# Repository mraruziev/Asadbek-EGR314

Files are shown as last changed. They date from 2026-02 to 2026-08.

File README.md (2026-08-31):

# CropSCOUT — from a class project to robot working

This repository is where CropSCOUT started: my individual datasheet for **EGR 314** at ASU Polytechnic, Spring 2026, as part of Team 202 — the Crop S.C.O.U.T.S.

The assignment was an exploration rover. Seven of us built one in four months. My subsystem was mobility: a custom PCB around an **ESP32-S3-WROOM-1** driving four DC motors, two LEDs and two buttons, handling daisy-chain UART and MQTT with the rest of the team's boards. Input takes anything from 5 V to 40 V, regulated to 3.3 V by an LM2596S-3.3 and to 5.5 V by an LM2575-5.5.

Everything below the fold — requirements, block diagram, component selection, BOM, schematic, PCB layout, the full subsystem API — is that class work, unchanged.

## What happened next

We showed the rover to farmers in Uzbekistan expecting notes on the electronics. They asked when they could buy one.

So we stopped guessing and asked properly. **We interviewed 30 farmers** in Jizzakh, Surkhandarya and Shakhrisabz — what they grow, what eats their time, what eats their money, and what they would actually pay for. The answers were blunt:

- **14 of 30** named weeding as the job that takes the most time. Spraying was second.
- **8 of the 29** who answered named spraying as their single largest cash cost in a season.
- **12 of 30** said seasonal labour is hard to find at all.
- Shown three concepts, **18 of 30** picked the universal platform — the biggest, most capable one — and rated it **4.5 out of 5**.

That last one changed the plan. We had designed a small rover; farmers kept asking for a bigger one that could do more than one job on the same base. The V2 CAD is being drawn around that.

The full results, including the answers that contradict our pitch, are published live at **[crop-scout.com/survey](https://crop-scout.com/survey/)** — every figure computed from the database as responses arrive.

## Where it lives now

| | |
|---|---|
| **[crop-scout.com](https://crop-scout.com)** | The robot: what it does, the interactive demo, the field research |
| **[bestarorg.uz](https://bestarorg.uz)** | The venture behind it, and our other projects |
| **[Presentation](https://www.canva.com/design/DAHR2F0Cv24/_gwUxZhiubCPhxlqnAkmqw/view)** | CropSCOUT deck |

CropSCOUT is backed by **UzCombinator**, Batch 2, 2026.

## Founders

**Asadbek Ruziev** — electronics. Robotics Engineering at ASU, El-Yurt Umidi scholar. CAN-bus, motor control, the boards.

**Asror Uralov** — mechanical. Chassis, arms and attachment systems in SolidWorks.

**Samandar** — manufacturing engineer

## The code

The mobility subsystem runs MicroPython on the ESP32-S3: MQTT over TLS for commands and telemetry, a UART daisy chain to the other boards, and closed-loop control of the four motors.

**[`Motor subsystem/`](https://github.com/mraruziev/Asadbek-EGR314/tree/main/Motor%20subsystem)** — `main.py` (633 lines), `config.py`, and the `mqtt_as` async client.

## Demo

CropSCOUT demo (https://youtu.be/CgNYh9vksoY?si=Wh2rkczbTwafdUjh)

▶ **[Watch the demo](https://youtu.be/CgNYh9vksoY?si=Wh2rkczbTwafdUjh)**

## The datasheet

Live site: **[mraruziev.github.io/Asadbek-EGR314](https://mraruziev.github.io/Asadbek-EGR314/)**
Team 202 report: **[egr314-s-2026-202.github.io](https://egr314-s-2026-202.github.io/)**

Built with the rest of Team 202: Caleb Yuen, Cristopher Gutierrez, Jacob Alger, Aaron Kiem and Isaiah Johnston.
>>>>>>> d1ab0351fcce91105b6e6388854c63e64ff8db13

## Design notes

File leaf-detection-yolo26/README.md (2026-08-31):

# Leaf Detection YOLO26 Subsystem

Python subsystem for realtime leaf detection with Ultralytics YOLO26, PlantDoc object-detection training data, and PlantVillage/Chinese classification data for disease labeling.

## On macOS?

See `docs/macos_quickstart.md`. The commands below are PowerShell and assume CUDA;
the macOS path uses `--device mps`, needs no Kaggle or Roboflow account, and gets you
a working webcam demo with:

```bash
./.venv/bin/leaf-download-plantvillage-hf --out data/processed/plantvillage_cls
./.venv/bin/leaf-train classify --config configs/training/classify_plantvillage.yaml --epochs 8 --batch 64 --device mps
./.venv/bin/python webcam.py
```

## Current Assumptions

- `YOLO26` means the current Ultralytics YOLO26 family, starting with `yolo26n.pt` for realtime detection.
- `PlantDoc` is the primary detector dataset because it has bounding boxes.
- `PlantVillage` is image-level classification data, so it feeds the classifier branch by default. Pseudo-box conversion is available only for baseline experiments.
- The requested Chinese dataset is treated as the AI Challenger 2018 Agricultural Disease dataset unless you specify a different source.
- Claude is not invoked by this repo. `CLAUDE.md` is included so Claude Code can safely pick up context if you run it separately.

## Setup

```powershell
cd C:\Users\abbos\source\leaf-detection-yolo26
python -m venv .venv
.\.venv\Scripts\Activate.ps1
python -m pip install --upgrade pip
pip install -r requirements.txt
pip install -e .
```

For GPU training, install the PyTorch build matching your CUDA version before installing `ultralytics`.

## Data Layout

```text
data/
  raw/
    plantdoc/                 # Roboflow YOLO export with data.yaml
    plantvillage/             # Kaggle download
    chinese/                  # Requested dataset when received
  processed/
    plantvillage_cls/         # YOLO classification folder layout
    plantvillage_pseudo_yolo/ # Optional weak detection labels
runs/
  detect/
  classify/
```

## Download PlantDoc

Preferred path is a Roboflow YOLOv8/YOLO export.

```powershell
copy .env.example .env
# Fill ROBOFLOW_API_KEY in .env
leaf-download-plantdoc --out data/raw/plantdoc
leaf-validate-yolo --dataset data/raw/plantdoc
```

If Roboflow gives you a direct export ZIP URL:

```powershell
leaf-download-plantdoc --url "https://..." --out data/raw/plantdoc
```

## Download PlantVillage

Install Kaggle credentials as `%USERPROFILE%\.kaggle\kaggle.json` or set `KAGGLE_USERNAME` and `KAGGLE_KEY`.

```powershell
leaf-download-plantvillage --dataset emmarex/plantdisease --out data/raw/plantvillage
leaf-prepare-plantvillage --source data/raw/plantvillage --out data/processed/plantvillage_cls --overwrite
```

## Train

Detector:

```powershell
leaf-train detect --config configs/training/detect_plantdoc.yaml
```

Classifier:

```powershell
leaf-train classify --config configs/training/classify_plantvillage.yaml
```

Dry-run either command before spending GPU time:

```powershell
leaf-train detect --config configs/training/detect_plantdoc.yaml --dry-run
```

## Realtime Inference

Disease classifier only, no detector weights needed. The classifier reads a centre
crop of the frame, so fill that box with one leaf:

```powershell
leaf-realtime --classifier runs/classify/plantvillage_yolo26n_cls/weights/best.pt --source 0
```

Detector only:

```powershell
leaf-realtime --detector runs/detect/plantdoc_yolo26n/weights/best.pt --source 0
```

Detector plus disease classifier:

```powershell
leaf-realtime `
  --detector runs/detect/plantdoc_yolo26n/weights/best.pt `
  --classifier runs/classify/plantvillage_yolo26n_cls/weights/best.pt `
  --source 0
```

Press `q` to stop the preview window.

## Export

```powershell
leaf-export --model runs/detect/plantdoc_yolo26n/weights/best.pt --format onnx --imgsz 640
```

Use TensorRT only on a matching NVIDIA deployment machine:

```powershell
leaf-export --model runs/detect/plantdoc_yolo26n/weights/best.pt --format engine --device 0 --half
```

## Optional Weak Detection From PlantVillage

PlantVillage does not provide bounding boxes. If you need one combined detector baseline anyway:

```powershell
leaf-pseudo-yolo --source data/processed/plantvillage_cls --out data/processed/plantvillage_pseudo_yolo --overwrite
```

This creates one full-image bounding box per classification image. Treat resulting metrics as a weak baseline, not as production detector quality.

## Source References

- Ultralytics YOLO26 detection/training/export docs: https://docs.ultralytics.com/tasks/detect/
- Ultralytics Python usage docs: https://docs.ultralytics.com/usage/python/
- PlantDoc Roboflow public dataset: https://public.roboflow.com/object-detection/plantdoc/
- PlantVillage Kaggle dataset requested: https://www.kaggle.com/datasets/emmarex/plantdisease?select=PlantVillage
- AI Challenger 2018 Chinese agricultural disease candidate: https://spj.science.org/doi/10.34133/plantphenomics.0208

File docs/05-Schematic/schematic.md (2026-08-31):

---
title: Module Schematic
---

### Overview
This schematic is designed to support 4 motors, motor drivers, ESP32 subsystem. I will also be sending and receiving data through TX and RX of the 8-pin headers. Some symbols were sourced from the Digikey website, while a few others were from the KiCad library.

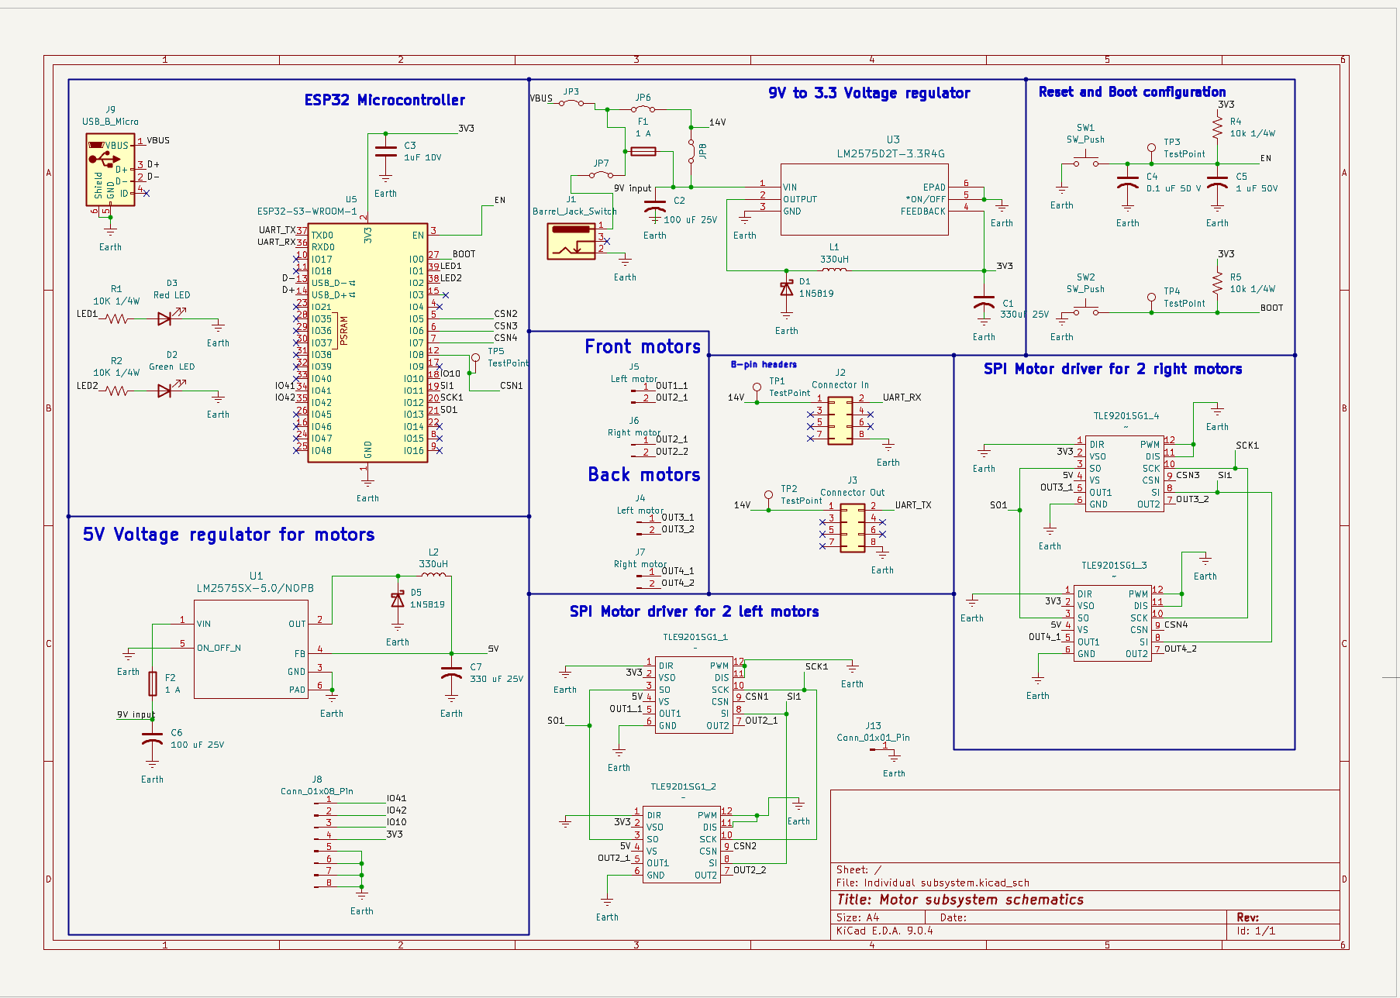
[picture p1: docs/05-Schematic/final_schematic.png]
schematic

**Figure 1:** Showing my schematic

### Key functional blocks

## 1. Microcontroller interface
* ESP32-S3-WROOM-1
* UART daisy chain interface 
* USB for programming
* Boot, reset buttons
* Extra pins for other potential usage
The ESP32 microcontroller is included in this schematic.

## 2. Motor Driver
* SPI configuration (SCLK, SDI, SDO, NSCS)
* PWM → PWM is not going to be used since it is SPI, so it will be grounded
* DIR → direction grounded (not used)
* DIS → enable/disable
* VSO 
I am also going to use 4 motor drivers. The motor driver is a surface-mount H-bridge. Out1 and Out2 allow control of the speed, and input comes from the GPIO pins of the ESP32, while output goes to the motors.

## 3. Shared SPI
* GPIO11 → SI on all drivers
* GPIO13 ← SO on all drivers
* GPIO12 → SCK on all drivers
Since I am going to use 4 motors together, I will have 3 shared SPI pins that go to the same ESP32 GPIO as above.

## 4. UART
* TX1
* RX1 
Since UART0 - TX0, RX0 gave me problems during the daisy chain, I updated the schematic to swap UART pins.

## 5. Motors
I am going to use 2 headers for each of my motors, as they can not be surface-mount. In total, I will be using 4 motors that will be working with 4 motor drivers.
* 200 RPM 3-6V DC Gearmotor

## 6. Power Management
* 9V barrel jack for motors
* LM2575D 3.3 Voltage regulator
* LM2575D 5.5 Voltage regulator for motor movement
* Fuse for both barrel jacks for safety
* The input power can be anywhere from 5V to 40 volts.
* If using team power, connect jumpers at JP6 and JP7
* For individual power supply, connect JP3
* For using motors with their own power, use JP7

## Resources

The schematic as a PDF download is available [*here*](Final_schematic.pdf), and the Zip folder of the project [*here*](EGR314-kicad-final.zip).

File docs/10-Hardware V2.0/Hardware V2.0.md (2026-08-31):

---
title: Module Hardware V2
---

### Overview
Improvement 1: If I were to make a new PCB, I would try to use.STL files from the Digikey design, so that before ordering the PCB, I know how my component aligns properly with the footprint. The footprint for the inductor was quite different than the actual size of the inductor I used. I would start my PCB design earlier, as most of my PCB problems were because I started it a bit late. 

<br> 
Improvement 2: I would also try to use Cadence next time with its auto-tracing feature, or trace components better on KiCad. My traces were too small, and this could have affected my motor driver. The power was not coming to my motor driver, even if I made 3 PCBs.

<br> 
Improvement 3: I would try to make my LEDs and resistors a bit bigger, allowing me to solder more easily, and since there are bigger surface-mount components available. I will try to research more on different sizes of components, allowing me to have a better design. 

<br> 
Improvement 4: I would also choose bigger wheels and bigger motors with high torque and more RPM. Also, I would try to use I2C-based motor drivers instead of SPI for my motors since my motors were working fine without a daisy chain. But when I was getting commands for motor movements, my motors would move endlessly and not accept other commands. This also means that my motor drivers will need more input power, so I would change my voltage regulator to a 12V regulator. 

<br>
Improvement 5: I would try to reduce the PCB size and make holes to mount the PCB. This would have been very helpful to reduce manufacturing costs and learn a better way.

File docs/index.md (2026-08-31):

---
title: Welcome
tags:
- tag1
- tag2
---
<center>
<font size= "6">Asadbek Ruziev Datasheet</font><br>
as part of<br>
<font size= "8"> Exploration Device Project</font><br>
for<br>
<font size= "5"> Crop S.C.O.U.T.S. </font><br>

<font size= "5"> Team 202 </font><br>

**Submission: May, 4, 2026**
</center>

## Introduction

* Hi! I am highly passionate about mobile robotics for agriculture and ecology. Through my work at CropSCOUT at EGR 314, I gained in-depth knowledge and experience that I plan on using in future projects.

### Project Summary

* I am responsible for mobillity of <ins>the rover project.</ins> We are a team of 7 engineering students who are designing an explorative rover in 4 months. Please, take a look at the process of our design through the different tabs in the team report. fF you would like to learn more about other team members' subsystems, access the team report and follow the link for each member's website.
* To get more information about our teamwork, follow Team 202 [Team report.](https://egr314-s-2026-202.github.io/)

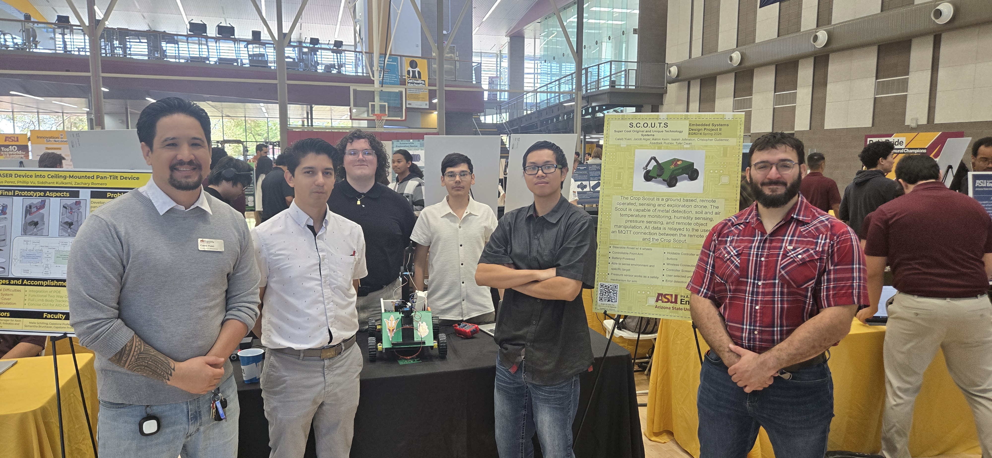
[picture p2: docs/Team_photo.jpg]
Team picture

>From left ro right: Cale Yuen, Cristopher Gutierrez, Jacob Alger, Asadbek Ruziev, Aaron Kiem, Isaiah Johnston

### My Contribution 

* Our team is focused on making a land-based explorative rover project that drives to different places and uses its sensors to perform measurements. The Crop Scout is a ground-based, remotely operated, sensing and exploration rover. It is capable of going to any place and detecting metal, measuring temperature, and humidity. All data works through an MQTT connection and a UART
* I am responsible for the mobility of the rover using ESP32. I will be using 4 motors with wheels attached. Motors will be working through the motor driver to move the robot from a distance through WiFi.

To review the details listed of the material used to construct the subsection, you can review it in the ["Team"](https://egr314-s-2026-202.github.io/) section of the datasheet.

## Showcase Video Demo

<iframe width="560" height="315" src="https://www.youtube.com/embed/CgNYh9vksoY?si=5lFRXKqbXAz6XXHL" title="YouTube video player" frameborder="0" allow="accelerometer; autoplay; clipboard-write; encrypted-media; gyroscope; picture-in-picture; web-share" referrerpolicy="strict-origin-when-cross-origin" allowfullscreen></iframe>

To review the details of the data sheet, hyperlinks are provided below: <br>
[1. Requirements](https://mraruziev.github.io/Asadbek-EGR314/01-Requirements/Requirements/) <br> 
[2. Block Diagram](https://mraruziev.github.io/Asadbek-EGR314/02-Block-Diagram/Block-Diagram/) <br> 
[3. BOM](https://mraruziev.github.io/Asadbek-EGR314/04-BOM/BOM/) <br> 
[4. Component Selection](https://mraruziev.github.io/Asadbek-EGR314/03-Component-Selection/Component-Selection/) <br> 
[5. Schematic](https://mraruziev.github.io/Asadbek-EGR314/05-Schematic/schematic/) <br> 
[6. PCB Design](https://mraruziev.github.io/Asadbek-EGR314/06-PCB/pcb/)  <br>
[7. API](https://mraruziev.github.io/Asadbek-EGR314/07-API/API/) <br>
[8. Schematic](https://mraruziev.github.io/Asadbek-EGR314/08-Resources/Resources/) <br> 
[9. Reflections](https://mraruziev.github.io/Asadbek-EGR314/09-Lessons%20Learned/Lessons%20learned/)  <br>
[10. Hardware V2.0](https://mraruziev.github.io/Asadbek-EGR314/10-Hardware%20V2.0/Hardware%20V2.0/) <br>
[11. Appendix](https://mraruziev.github.io/Asadbek-EGR314/Appendix/) <br>

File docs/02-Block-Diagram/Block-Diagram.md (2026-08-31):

---
title: Module's Block Diagram
tags:
- tag1
- tag2
---

## Overview
Purpose of having block diagram is to help visualise my subsystem so that you can understand the workflow of code and schematics better. I have included 2 motors that are going to be parallel on the right. 2 motors on the left will also work together. I have planned to make the rover working with 2 motors together on each side, then making chassis as my stretch goal. This block diagram clearly shows how power, control and data will be floweing through my subsystem and to make the whole rover system work. Mobility of the rover is crucial to successfull launch of the project.

<br> <br>

## Asadbek's Block Diagram 
Showing my screenshot of the block diagram here

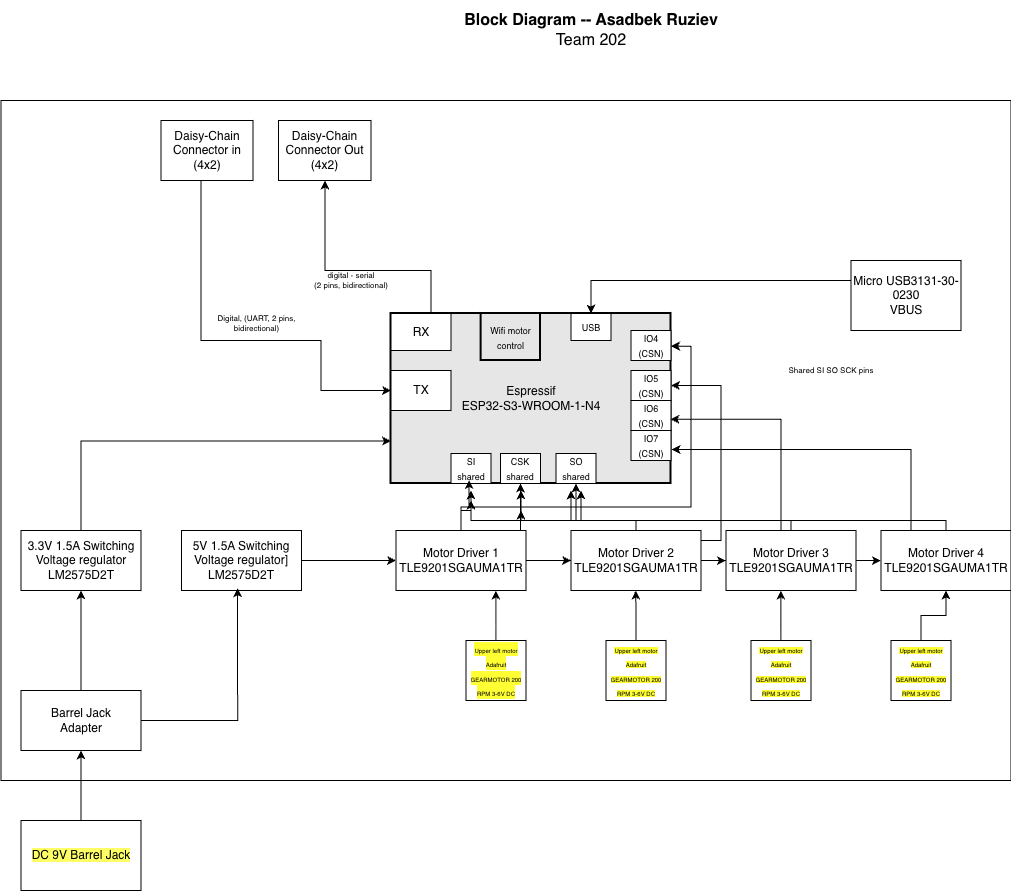
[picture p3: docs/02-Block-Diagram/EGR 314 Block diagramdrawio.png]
My Indivial Block diagram


### Impoortant Things to mention are following:
* ESP32-S3-WROOM-1
* 4 Motor Drivers
* 4 Motors
* Voltage regulator: 1 barrel jack  is going to be used twice through shared power for the team and inidividually. I will use 2 voltage regulatorsand one of them will be to convert voltage into the 3.3 V and 6V.
* Daisy chain connectors through 8-pin header connectors Connector In (4×2), Connector Out (4×2) and UART communication.
* USB
* Power levels: Unregulated power levels are going to be 9V for the motors, but the input to ESP 32 is 3.3V. For logic-level peripherals of my subsystem's ESP 32 I will use 3.3 volts. 
* Actuator: I will be using 4 same DC motors for smooth operation of the rover. 
* Team connections: I will be connecting my ESP32 to Caleb's board to oeprate better through RX and TX 
* Power source: barrel jack for the motors are main sources of power. 

SPI UART serial communication protocols are just alternative communication ways to connect to motors actuators sensor. All WiFi is done by esp32. 

Decision-making process: My block diagram meets project requirements by following the requirement TR-01(mobillity of the rover) and helping with Wi-Fi/MQTT of the rover.

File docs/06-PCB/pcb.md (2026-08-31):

---
title: PCB
---
## Overview
This section is an overview of the PCB design for the Metal detection system for the CropScout. Some of the footprints are from the Digikey.

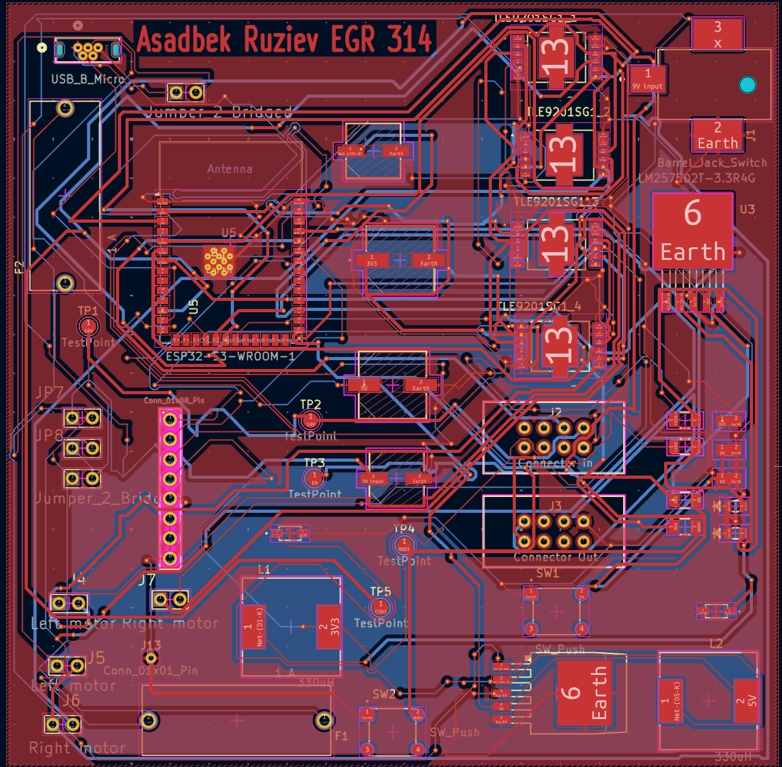
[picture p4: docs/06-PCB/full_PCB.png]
View


**Figure #1:** Full View of PCB.

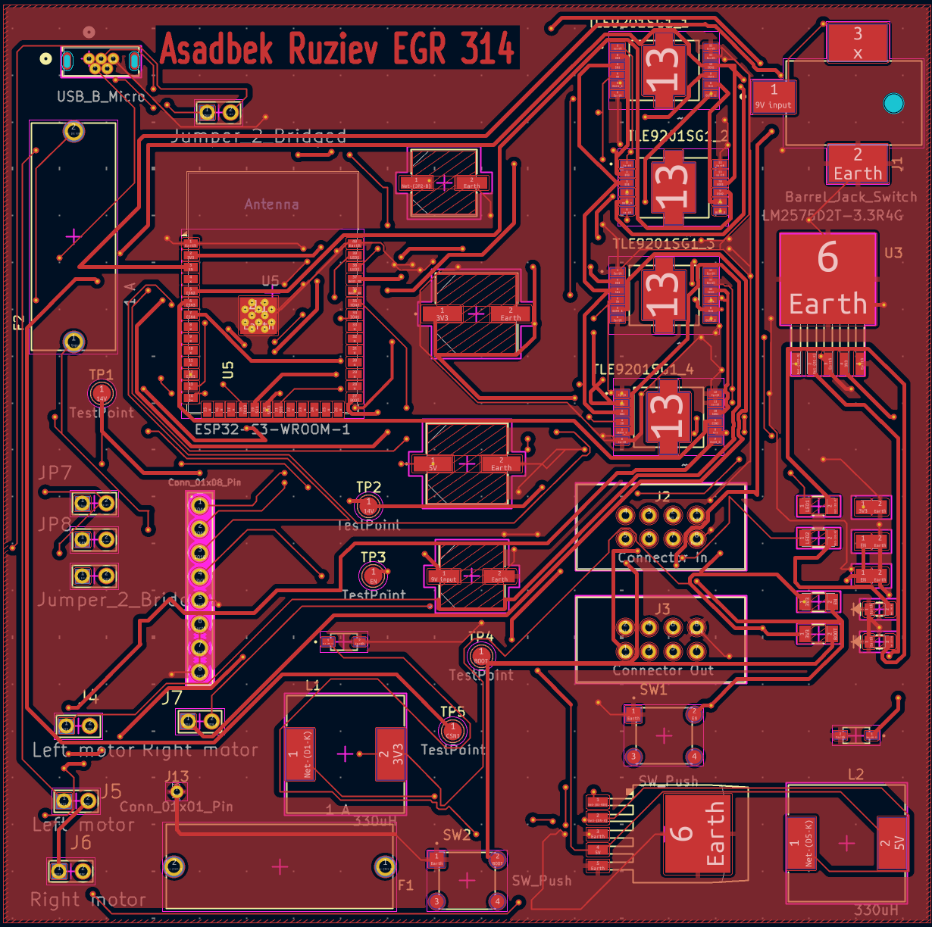
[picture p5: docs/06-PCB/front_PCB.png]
Front


**Figure #2:** Front View of PCB.

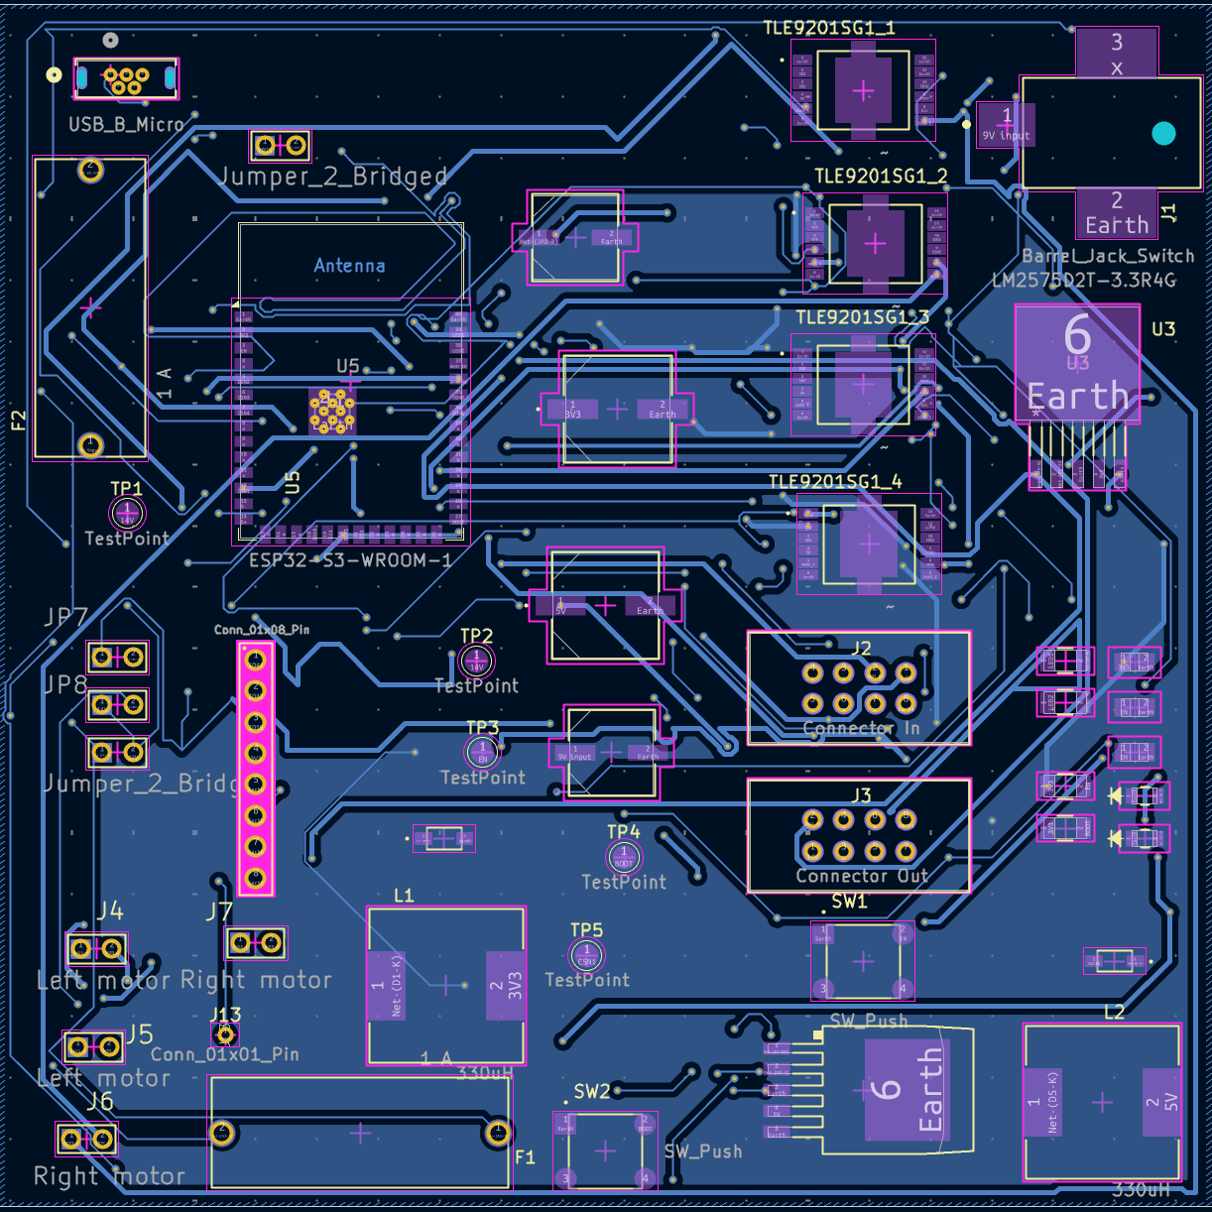
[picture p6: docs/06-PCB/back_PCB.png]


**Figure #3:** Back View of PCB.

<<<<<<< HEAD
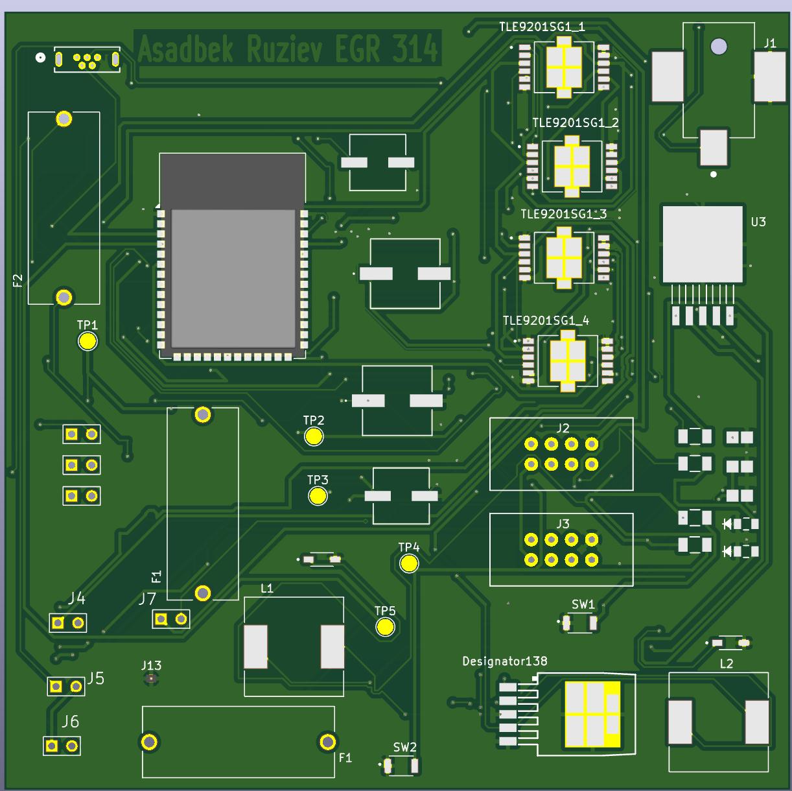
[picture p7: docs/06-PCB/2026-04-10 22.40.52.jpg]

=======
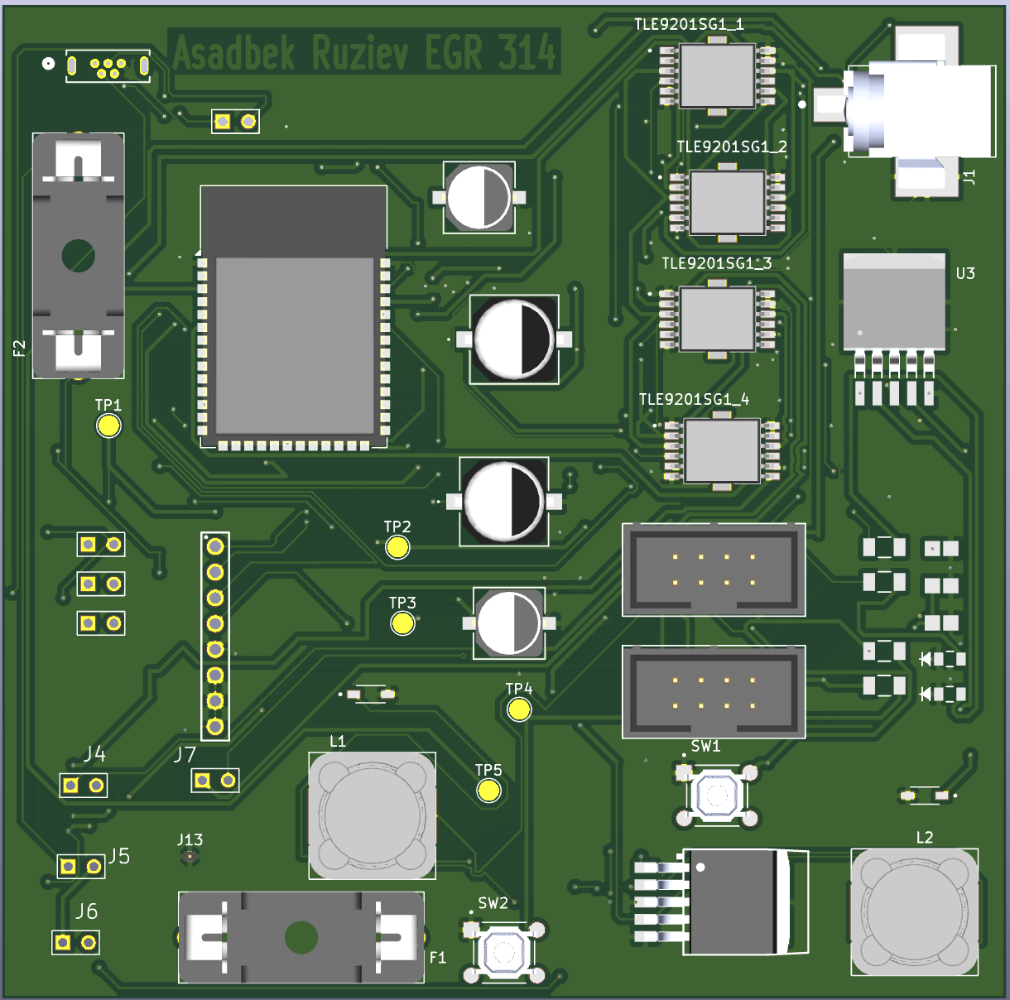
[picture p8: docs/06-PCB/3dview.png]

>>>>>>> d1ab0351fcce91105b6e6388854c63e64ff8db13

**Figure #4:** 3D View of PCB.

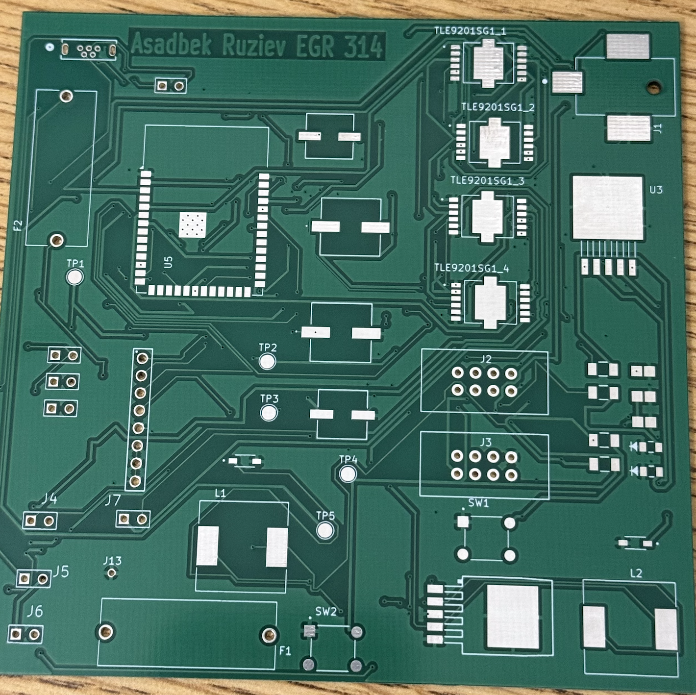
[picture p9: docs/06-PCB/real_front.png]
Front


**Figure #5:** FrManufactured Front View of PCB.

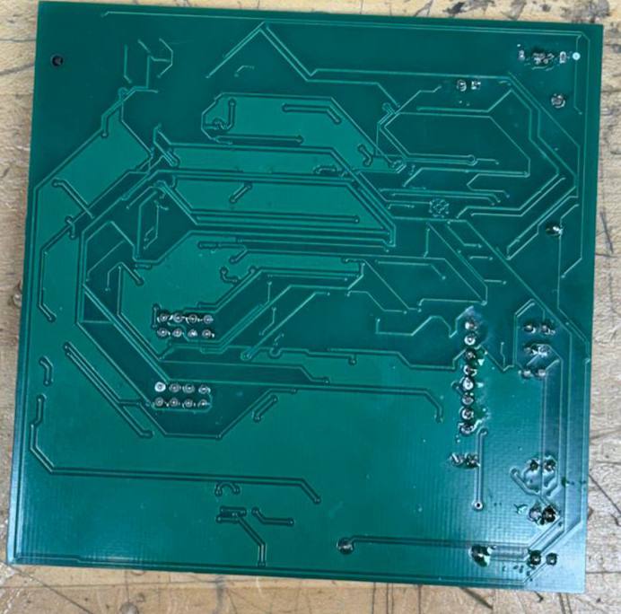
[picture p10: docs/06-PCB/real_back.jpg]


**Figure #6:** JLCPCB Back View of PCB.

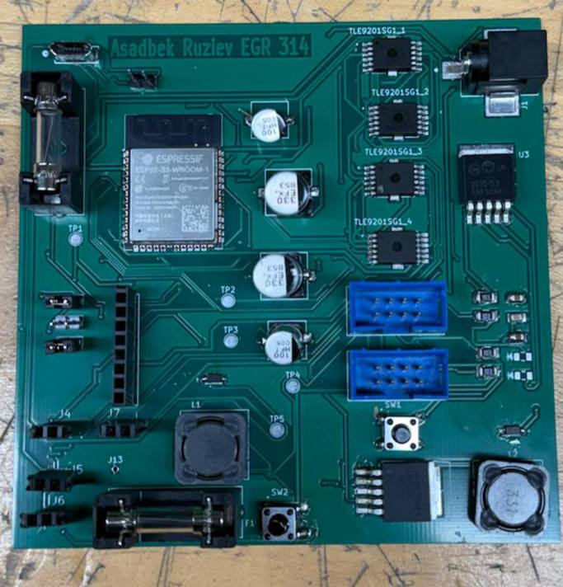
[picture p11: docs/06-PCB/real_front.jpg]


**Figure #7:** Soldered View of PCB connected to team Daisy Chain

**Resources**
Individual subsystem.zip

The zip folder of the project [*here*](Individual subsystem april version.zip).
The gerber files of the project [*here*](gerber.zip).

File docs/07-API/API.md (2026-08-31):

---
title: Mobillity API
---

## Overview
This page exists to show the API messaging of the Wheel and mobillity subsystem. API stands for Application Programming Interface.
The following are messages sent and received to my board. Some messages get passed from me, as my subsystem will check the message and send it to the next person.
The subsystem's ID is "w".

Cristopher sends me a message via MQTT/WiFi, and I verify it. I use it to send it back to him. He forwards it to Jacob. Jacob will share the wheel commands with my board. Each message will have a destination type instead of being a loop source. It is also broadcasted used for everyone. Messages will be done one by one, as it is a daisy chain.

### All Subsystem IDs

| Subsystem | Identifier | Person |
| --- | --- | --- |
| HMI | h | Jacob |
| Communication | c | Cris |
| Wheels | w | Asadbek |
| Pressure/Accelerometer  | p | Tyler |
| Front Arm | a | Caleb |
| Metal Detector | m | Aaron |
| Temperature/Humidity | t | Isaiah |
| Broadcast | X | System-Wide Messaging |

## Message data types

| Description | Prefix |
| --- | --- |
| String (ASCII char array)| S: |
| Integer (8 Bit) | I: |
| Integer (16 Bit) | IL: |
| Float (32 Bit) | F: |

## Received Messages
- Message framing for single-character subsystem IDs 
- AZ [Sender] [Receiver] [Data in the message (1-58 bytes) ] BY
- | WD:S:F |
- | WD:S:B |
- | WD:S:R |
- | WD:S:L |
The wheel subsystem will receive drive commands from the HMI and start broadcasting. Those commands are processed and sent back to the HMI with the values I receive over UART.

If Jacob/HMI is commanding wheels:
* Forward: AZhwWD:S:F;YB
* Backward: AZhwWD:S:B;YB
* Right: AZhwWD:S:R;YB
* Left: AZhwWD:S:L;YB
Start broadcast to everyone:
* AZhXST:S:Start;YB
If Chris/Communication is checking wheel Bluetooth:
* AZcwBT:S:check;YB
If you want to force-stop for testing, your current wheel code also supports:
* AZhwWD:S:S;YB

### Message Type -- Start Broadcast

As shown above, this is broadcast message for my board: `AZhXST:S:Start;YB`

| Bytes 1–3 | Bytes 4–5 | Bytes 6–11 |
| --- | --- | --- |
| **Name** | **Type**  | **Data** |
| ST: | S: | Start; |
| **Min** | | Start; |
| **Max** | | Start; |
| **Example** ST: | S: | Start; |

### Message Type -- Wheel Drive Mode

Receives the direction command from the HMI D-Pad and drives the wheels accordingly.

`AZhwWD:S:F;YB`

| Bytes 1–3 | Bytes 4–5 | Bytes 6–7 |
| --- | --- | --- |
| **Name** | **Type**  | **Data** |
| WD: | S: | F; / B; / R; / L; |
| **Min** | | F; / B; / R; / L; |
| **Max** | | F; / B; / R; / L; |
| **Example** WD: | S: | F; |

## Behaviour check
- Check whether the format of the message packet is valid
- Check if it is for the wheel subsystem
- Check the destination if not

## Receiving messages

When a byte comes through the UART/MQTT to my board
1. Look for the AZ packet prefix, and anything non-related is discarded
2. I read bytes into a buffer till suffix BY is found or the buffer limit of 62 bytes is exceeded.
3. If receiver == w (my board), the message is parsed
4. If receiver == X (broadcast), the message is parsed and processed
5. If the message receiver is not me, the packet is going to be forwarded out the downstream UART byte-for-byte

| Section | Bytes amount | Name of the variable | Tpe ID | Example for the code |
| :---- | :---- | :---- | :---- | :---- |
| Type ID | 5 | S | char | S |
| Variable | 2 | WD | char | WD |
| Seperator | 1 |  | char | : |
| Terminator value | 1 | DRCTN | char | : |
| Value | 1 |  | char |  |

Overall message bytes: 12

## Sending messages
| Section | Bytes amount | Name of the variable | Tpe ID | Example for the code |
| :---- | :---- | :---- | :---- | :---- |
| Type ID | 5 | S | char | S |
| Variable | 1 | : | char | ST |
| Seperator | 1 | : | char | : |
| Terminator value | 1 | DRCTN | char | : |
| Value | 1 | Start | char | Start |

Overall message bytes: 12

Example: AZhXST:S:Start;YB

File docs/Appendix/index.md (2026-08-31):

---
title: Appendix - Main Page
---

>The Appendix is where supporting information goes that is not in the main body. 

## Appendix Content

* [Microcontroller selection](https://mraruziev.github.io/Asadbek-EGR314/Appendix/02-Microcontroller-Selection/esp-32-table/)
* [Power budget](https://mraruziev.github.io/Asadbek-EGR314/Appendix/02-Power-Budget/Power-Budget/)

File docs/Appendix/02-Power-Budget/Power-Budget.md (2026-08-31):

---
title: Appendix - Power Budget
---

## Overview
Power Budget helps to understand more about the maximum current draw. This helsp to understand the choice of appropariate fuse. The power budget also helps to know if the subsystem is going to operate in different current scenarios.

> Capture your power budge as a image to display. Take time to get clean breaks and a well organized layout.

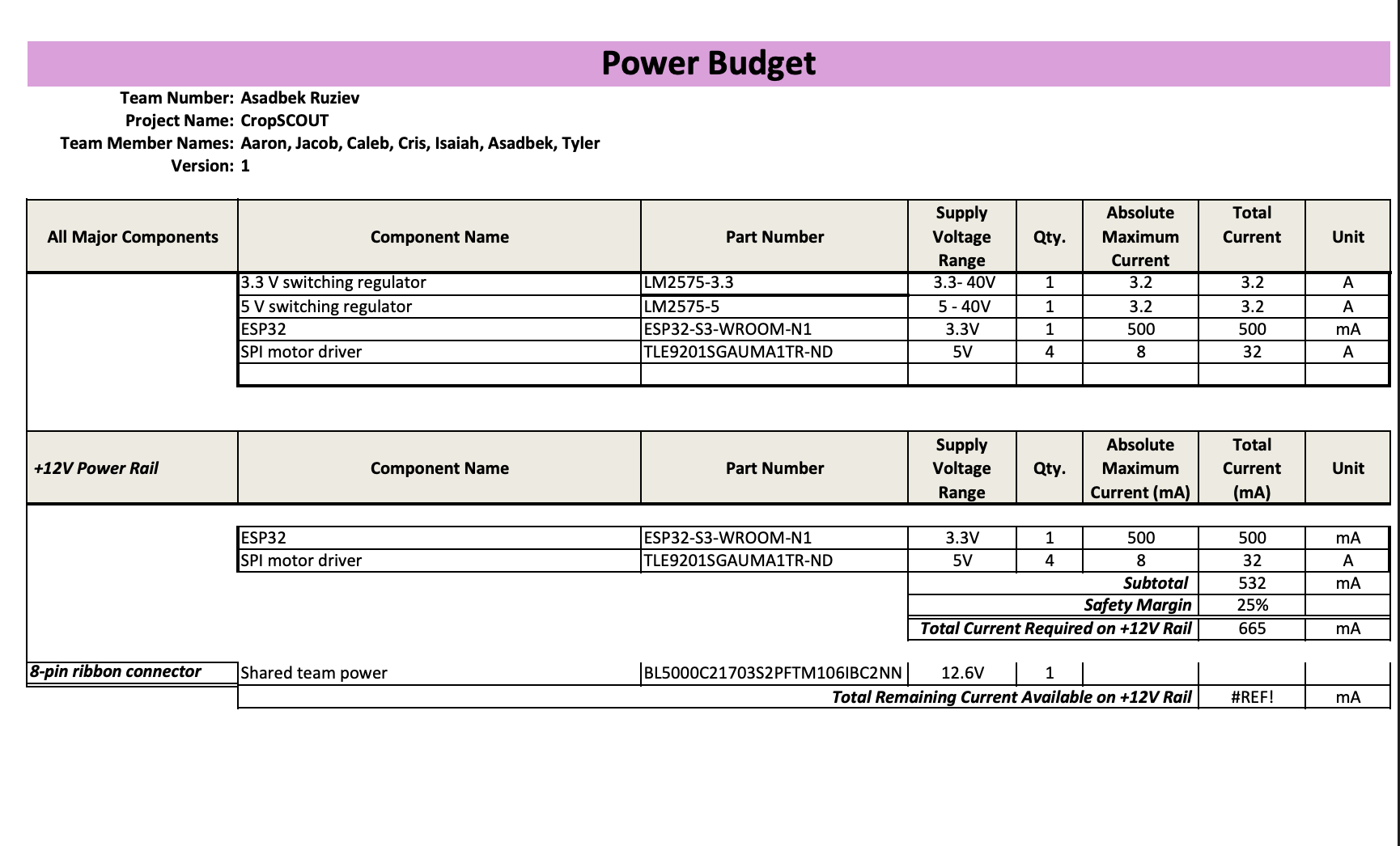
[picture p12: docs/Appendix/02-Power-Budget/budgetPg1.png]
budget1


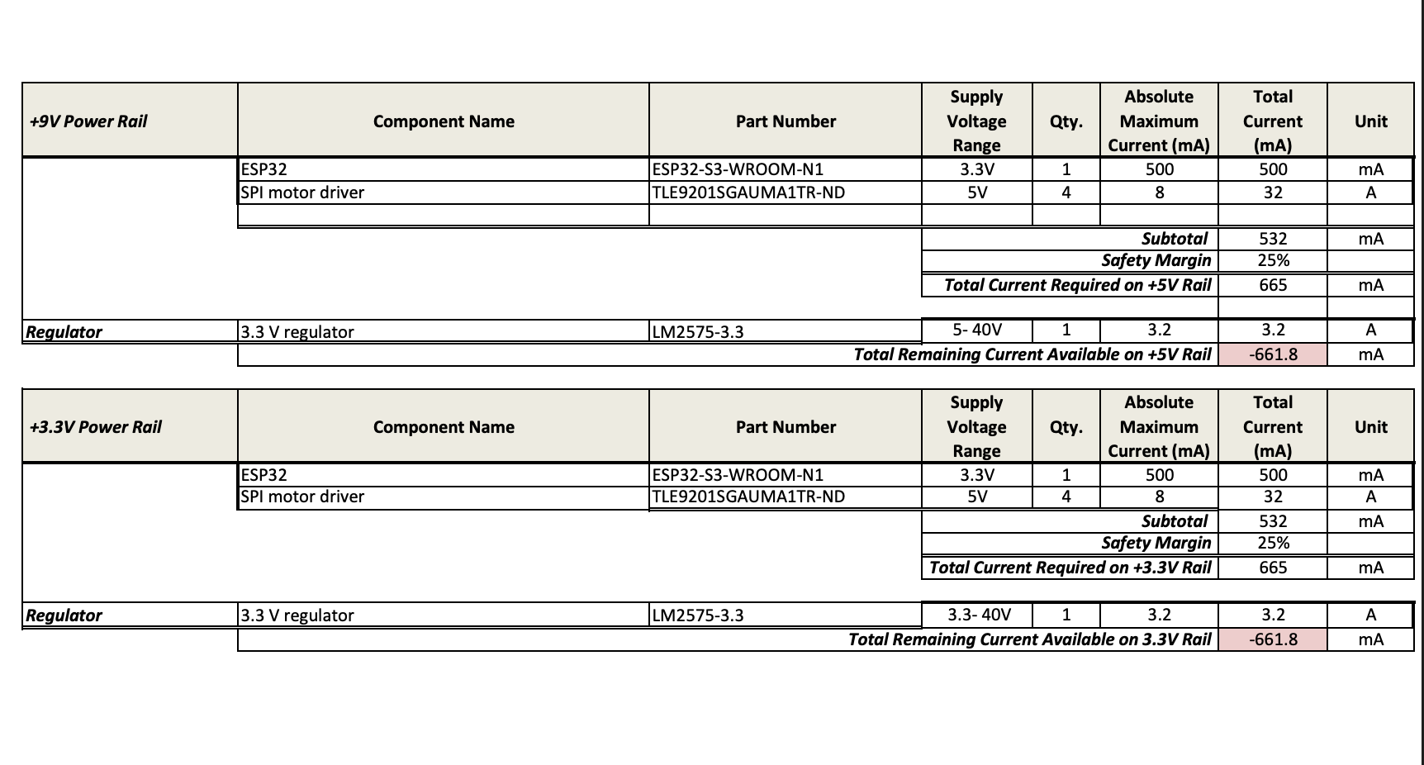
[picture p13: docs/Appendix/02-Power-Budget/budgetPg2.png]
budget2


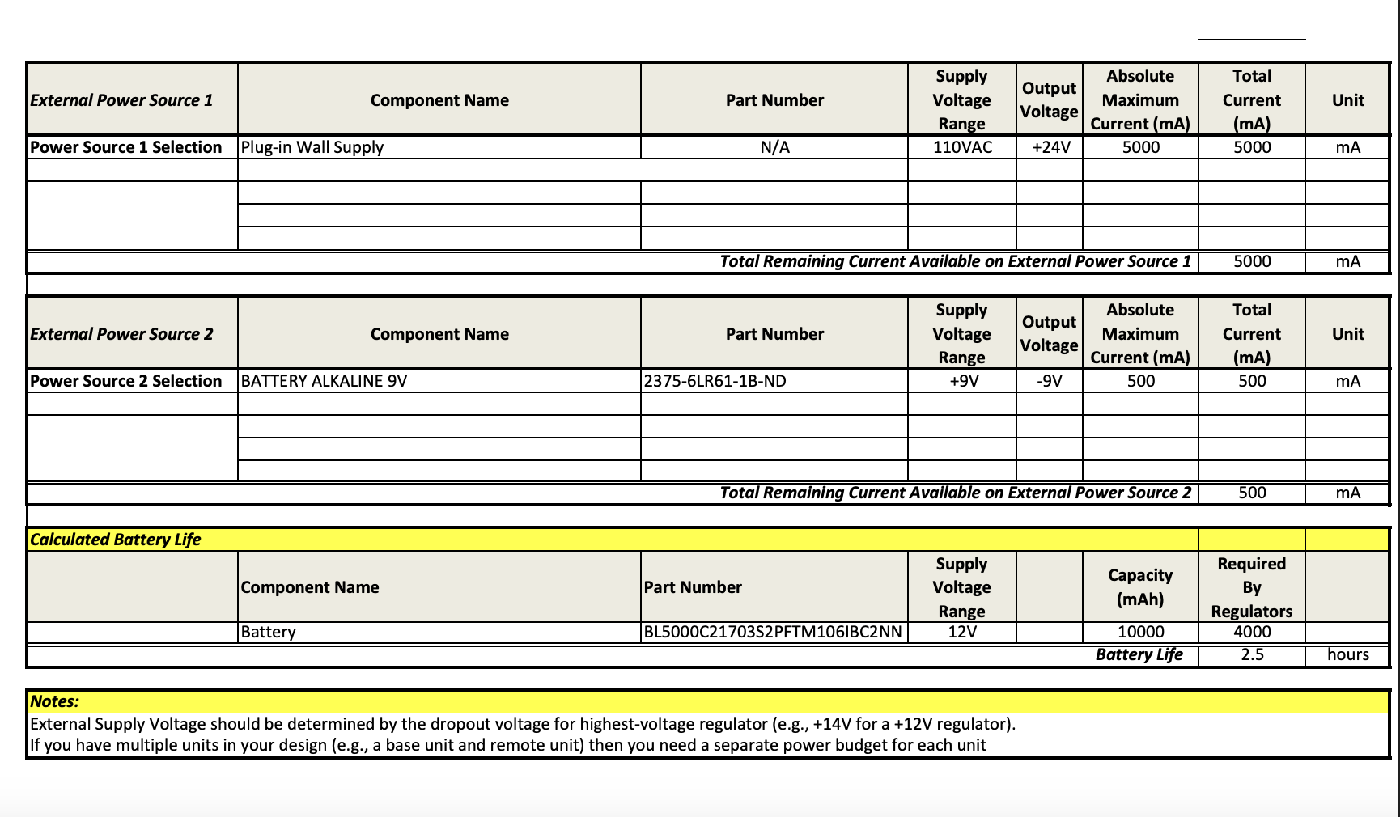
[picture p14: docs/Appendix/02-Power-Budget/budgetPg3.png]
budget3


## Conclusions

Power Budget helped me a lot to understand my current for ESP32 and to choose good fuse. I also was able to have board working without any problems.

## Resouces

The power budget as a PDF download is available [*here*](PowerBudget_EGR314.pdf), and a Microsoft Excel Sheet [*here*](PowerBudgeexcel.xlsx).

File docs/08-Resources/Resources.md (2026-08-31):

---
title: Module Lessons
---

### Overview

## Project code
* Following is my Zip for the code available for download from [*here*](Motor subsystem.zip).

* To run it, make sure to use either pymaker or mpremote on the VS code. I would highly suggest using mpremote to download the code to the ESP32. To do that, download the mpremote library from VS code.

## Use following commands on terminal, once you open the folder on VS code and set up the mpremote: 

* To use the ESP32, type in the terminal: mpremote connect auto
* To program ESP32 type: mpremote fs ls -r

<iframe width="560" height="315" src="https://www.youtube.com/embed/CgNYh9vksoY?si=5lFRXKqbXAz6XXHL" title="YouTube video player" frameborder="0" allow="accelerometer; autoplay; clipboard-write; encrypted-media; gyroscope; picture-in-picture; web-share" referrerpolicy="strict-origin-when-cross-origin" allowfullscreen></iframe>

---
## Individual motor code

```python title="main.py"
import machine
import time

SCK_PIN = 12
SI_PIN = 11
SO_PIN = 13

# From your schematic
CS_FRONT_LEFT  = 5   # CSN1
CS_FRONT_RIGHT = 6    # CSN2
CS_BACK_LEFT   = 7    # CSN3
CS_BACK_RIGHT  = 8    # CSN4

WR_FORWARD = 0xFF
WR_REVERSE = 0xFD
WR_STOP    = 0xF8

spi = machine.SPI(
    2,
    baudrate=1000000,
    polarity=0,
    phase=1,
    sck=machine.Pin(SCK_PIN),
    mosi=machine.Pin(SI_PIN),
    miso=machine.Pin(SO_PIN),
)

fl = machine.Pin(CS_FRONT_LEFT, machine.Pin.OUT, value=1)
fr = machine.Pin(CS_FRONT_RIGHT, machine.Pin.OUT, value=1)
bl = machine.Pin(CS_BACK_LEFT, machine.Pin.OUT, value=1)
br = machine.Pin(CS_BACK_RIGHT, machine.Pin.OUT, value=1)

time.sleep(0.1)

def send_one(cs_pin, cmd_byte):
    cs_pin.value(0)
    time.sleep_us(2)
    spi.write(bytearray([cmd_byte]))
    time.sleep_us(2)
    cs_pin.value(1)
    time.sleep_us(2)

def stop_all():
    for cs in (fl, fr, bl, br):
        send_one(cs, WR_STOP)

def move_forward():
    send_one(fl, WR_FORWARD)
    send_one(fr, WR_REVERSE)
    send_one(bl, WR_FORWARD)
    send_one(br, WR_REVERSE)

def move_backward():
    send_one(fl, WR_REVERSE)
    send_one(fr, WR_FORWARD)
    send_one(bl, WR_REVERSE)
    send_one(br, WR_FORWARD)

print("4 motors ready")

try:
    while True:
        move_forward()
        print("forward")
        time.sleep(2)

        move_backward()
        print("backward")
        time.sleep(2)

except KeyboardInterrupt:
    stop_all()
    print("Program stopped")

```

---

To see the full code with Daisy Chain, please download the Zip file and use it through VS Code

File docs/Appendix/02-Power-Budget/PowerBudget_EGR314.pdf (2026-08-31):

Team Number: Asadbek Ruziev
Project Name: CropSCOUT
Team Member Names: Aaron, Jacob, Caleb, Cris, Isaiah, Asadbek, Tyler
Version: 1
All Major Components | Component Name | Part Number | Supply Voltage Range | Qty. | Absolute Maximum Current | Total Current | Unit
| 3.3 V switching regulator | LM2575-3.3 | 3.3- 40V | 1 | 3.2 | 3.2 | A
| 5 V switching regulator | LM2575-5 | 5 - 40V | 1 | 3.2 | 3.2 | A
| ESP32 | ESP32-S3-WROOM-N1 | 3.3V | 1 | 500 | 500 | mA
| SPI motor driver | TLE9201SGAUMA1TR-ND | 5V | 4 | 8 | 32 | A
+12V Power Rail | Component Name | Part Number

Supply
Voltage
Range

Qty.

Absolute
Maximum
Current (mA)

Total
Current
(mA)

Unit

ESP32 | ESP32-S3-WROOM-N1 | 3.3V | 1 | 500 | 500 | mA
SPI motor driver | TLE9201SGAUMA1TR-ND | 5V | 4 | 8 | 32 | A
| | Subtotal | | | 532 | mA
| | Safety Margin | | | 25%
| | Total Current Required on +12V Rail | | | 665 | mA
8-pin ribbon connector | Shared team power | BL5000C21703S2PFTM106IBC2NN | 12.6V | 1
#REF! | mA

# Power Budget

Total Remaining Current Available on +12V Rail

+9V Power Rail | Component Name | Part Number | Supply Voltage Range | Qty. | Absolute Maximum Current (mA) | Total Current (mA) | Unit
| ESP32 | ESP32-S3-WROOM-N1 | 3.3V | 1 | 500 | 500 | mA
| SPI motor driver | TLE9201SGAUMA1TR-ND | 5V | 4 | 8 | 32 | A
Subtotal | 532 | mA
Safety Margin | 25%
Total Current Required on +5V Rail | 665 | mA
Regulator | 3.3 V regulator | LM2575-3.3 | 5- 40V | 1 | 3.2 | 3.2 | A
| Total Remaining Current Available on +5V Rail | | | | | -661.8 | mA
+3.3V Power Rail | Component Name | Part Number | Supply Voltage Range | Qty. | Absolute Maximum Current (mA) | Total Current (mA) | Unit
| ESP32 | ESP32-S3-WROOM-N1 | 3.3V | 1 | 500 | 500 | mA
| SPI motor driver | TLE9201SGAUMA1TR-ND | 5V | 4 | 8 | 32 | A
| | | Subtotal | | | 532 | mA
| | | Safety Margin | | | 25%
| | | Total Current Required on +3.3V Rail | | | 665 | mA
Regulator | 3.3 V regulator | LM2575-3.3 | 3.3- 40V | 1 | 3.2 | 3.2 | A
| Total Remaining Current Available on 3.3V Rail | | | | | -661.8 | mA

External Power Source 1 | Component Name | Part Number | Supply Voltage Range | Output Voltage | Absolute Maximum Current (mA) | Total Current (mA) | Unit
Power Source 1 Selection | Plug-in Wall Supply | N/A | 110VAC | +24V | 5000 | 5000 | mA
5000 | mA
External Power Source 2 | Component Name | Part Number | Supply Voltage Range | Output Voltage | Absolute Maximum Current (mA) | Total Current (mA) | Unit
Power Source 2 Selection | BATTERY ALKALINE 9V | 2375-6LR61-1B-ND | +9V | -9V | 500 | 500 | mA
500 | mA

External Supply Voltage should be determined by the dropout voltage for highest-voltage regulator (e.g., +14V for a +12V regulator). If you have multiple units in your design (e.g., a base unit and remote unit) then you need a separate power budget for each unit

Total Remaining Current Available on External Power Source 2

Calculated Battery Life
| Component Name | Part Number | Supply Voltage Range | Capacity (mAh) | Required By Regulators
| Battery | BL5000C21703S2PFTM106IBC2NN | 12V | 10000 | 4000
Battery Life | | | | | 2.5 | hours

Notes:

Total Remaining Current Available on External Power Source 1

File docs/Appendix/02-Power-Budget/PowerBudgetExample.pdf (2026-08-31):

Team Number: ###
Project Name: EGR 304 Thing Team Member Names: Tom, Sam, John, Jane
Version: ##
All Major Components | Component Name | Part Number | Supply Voltage Range | Qty. | Absolute Maximum Current (mA) | Total Current (mA) | Unit
| Solenoid | (full part number) | +12 - 24V | 1 | 500 | 500 | mA
| Stepper motor | (full part number) | +12 - 24V | 1 | 300 | 300 | mA
| PSoC™ 4 BLE Module | (full part number) | (range) | 2 | 200 | 400 | mA
| Opamp | (full part number) | +5 to -5 | 1 | 100 | 100 | mA
| 5V regulator | (full part number) | +5V - 35V | 1 | 1000 | 1000 | mA
| Wifi transceiver | (full part number) | +1.8 - 3.3V | 1 | 350 | 350 | mA
+12V Power Rail | Component Name | Part Number | Supply Voltage Range | Qty. | Absolute Maximum Current (mA) | Total Current (mA) | Unit
| Solenoid | (full part number) | +12 - 24V | 1 | 500 | 500 | mA
| Stepper motor | (full part number) | +12 - 24V | 1 | 300 | 300 | mA
| | | | | | 0 mA
| | | Subtotal | | | 800 mA
| | | Safety Margin | | | 25%
| | | Total Current Required on +12V Rail | | | 1000 mA
Regulator | +12V regulator | LM7812 | +12V - 35V | 1 | 1000 | 1000 | mA
| Total Remaining Current Available on +12V Rail | | | | | 0 mA

# Power Budget Example

+5V Power Rail | Component Name | Part Number | Supply Voltage Range | Qty. | Absolute Maximum Current (mA) | Total Current (mA) | Unit
| PSoC™ 4 BLE Module | (full part number) | (range) | 2 | 200 | 400 | mA
| Opamp | (full part number) | (range) | 1 | 100 | 100 | mA
| | | | | | 0 mA
| | | Subtotal | | | 500 mA
| | | Safety Margin | | | 25%
| | | Total Current Required on +5V Rail | | | 625 mA
Regulator | +5V Regulator | LM7805 | (range) | 1 | 1000 | 1000 | mA
| Total Remaining Current Available on +5V Rail | | | | | 375 mA
+3.3V Power Rail | Component Name | Part Number | Supply Voltage Range | Qty. | Absolute Maximum Current (mA) | Total Current (mA) | Unit
| Wi-Fi transceiver | (full part number) | +1.8 - 3.3V | 1 | 350 | 350 | mA
| | | | | | 0 mA
| | | Subtotal | | | 350 mA
| | | Safety Margin | | | 25%
| | | Total Current Required on +3.3V Rail | | | 437.5 mA
Regulator | +3.3V low-dropout regulator | KA78RM33RTF | +5V - 20V | 1 | 500 | 500 | mA
| Total Remaining Current Available on 3.3V Rail | | | | | 62.5 mA

External Power Source 1 | Component Name | Part Number | Supply Voltage Range | Output Voltage | Absolute Maximum Current (mA) | Total Current (mA) | Unit
Power Source 1 Selection | Plug-in Wall Supply | (full part number) | 110VAC | +24V | 5000 | 5000 | mA
Power Rails Connected to External Power Source 1 | +12V regulator | LM7812 | +12V - 35V | 1 | 1000 | 1000 | mA
| +5V Regulator | LM7805 | (range) | 1 | 1000 | 1000 | mA
| +3.3V low-dropout regulator | KA78RM33RTF | +5V - 20V | 1 | 500 | 500 | mA
Total Remaining Current Available on External Power Source 1 | | | | | | 2500 mA
External Power Source 2 | Component Name | Part Number | Supply Voltage Range | Output Voltage | Absolute Maximum Current (mA) | Total Current (mA) | Unit
Power Source 2 Selection | Battery | (full part number) | +9V | -9V | 500 | 500 | mA
-5V Regulator | (full part number) | (range) | 1 | 500 | 500 | mA

### 0 mA

External Supply Voltage should be determined by the dropout voltage for highest-voltage regulator (e.g., +14V for a +12V regulator). If you have multiple units in your design (e.g., a base unit and remote unit) then you need a separate power budget for each unit

Power Rails Connected to
External Power Source 2
Total Remaining Current Available on External Power Source 2

Calculated Battery Life
| Component Name | Part Number | Supply Voltage Range | Capacity (mAh) | Required By Regulators
| Battery | (full part number) | +12V | 500 | 500
Battery Life | | | | | 1 | hours

Notes:

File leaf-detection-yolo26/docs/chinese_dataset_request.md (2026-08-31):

# Chinese Dataset Request

## Target

Primary target: AI Challenger 2018 Agricultural Disease / Plant Disease Recognition dataset.

If you meant a different Chinese dataset, replace the dataset name and recipient before sending.

## Email Template

Subject: Request for authorized access to AI Challenger 2018 Agricultural Disease dataset

Hello,

I am requesting access to the AI Challenger 2018 Agricultural Disease / Plant Disease Recognition dataset for a computer vision project focused on realtime plant leaf disease detection and classification.

Project summary:

- Model family: Ultralytics YOLO26
- Initial object-detection dataset: PlantDoc
- Additional classification dataset: PlantVillage
- Intended use: research/prototyping first, with any production or commercial use subject to dataset license approval

Could you please confirm:

1. Whether the dataset is still available for download or access request.
2. The current license and allowed usage terms.
3. Whether annotations are image-level labels only or include bounding boxes.
4. Required citation or attribution text.
5. Any redistribution restrictions for trained model weights.

If approved, please share the current access process or download instructions.

Thank you,

[Your name]

## After Access Is Granted

If the dataset has image-level labels:

```powershell
leaf-prepare-json-cls `
  --images data/raw/chinese/images `
  --annotations data/raw/chinese/AgriculturalDisease_train_annotations.json `
  --out data/processed/chinese_cls `
  --image-field image_id `
  --class-field disease_class `
  --overwrite
```

If the dataset has YOLO detection labels:

```powershell
leaf-validate-yolo --dataset data/raw/chinese
leaf-train detect --data data/raw/chinese/data.yaml --name chinese_yolo26n
```

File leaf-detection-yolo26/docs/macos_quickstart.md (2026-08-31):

# macOS Quickstart (Apple Silicon)

The main `README.md` is written for Windows PowerShell. This is the macOS path, and it
skips the Roboflow and Kaggle accounts entirely.

## What runs today

Webcam plant disease classification: hold a leaf in the centre box and the model names
the plant and the disease. This uses the classifier branch only, so no detector weights
and no Roboflow key are needed.

## 1. Environment

```bash
cd ~/leaf-detection-yolo26
python3 -m venv .venv
./.venv/bin/pip install --upgrade pip
./.venv/bin/pip install -r requirements-macos.txt
./.venv/bin/pip install -e .
```

`requirements-macos.txt` drops `roboflow` and `kaggle` (neither is needed for the Hugging
Face data path) and adds `huggingface_hub` plus `pyarrow`.

## 2. Camera permission

macOS blocks camera access until you approve the app that launches Python. Without it you
get `OpenCV: not authorized to capture video`.

System Settings > Privacy & Security > Camera, then enable the app you run the script
from (Terminal, iTerm, VS Code, or Claude). Quit and reopen that app afterwards — the
permission only takes effect on a fresh launch.

## 3. Data

No Kaggle account required. PlantVillage comes from a public Hugging Face mirror:

```bash
./.venv/bin/leaf-download-plantvillage-hf --out data/processed/plantvillage_cls
```

That writes 43,503 training and 10,878 validation images across 38 classes
(about 900 MB) in the folder layout `yolo classify` expects.

## 4. Train the disease classifier

`batch: -1` (Ultralytics AutoBatch) is CUDA-only, so set a batch size explicitly and
point at the Apple GPU with `--device mps`:

```bash
./.venv/bin/leaf-train classify \
  --config configs/training/classify_plantvillage.yaml \
  --epochs 8 --batch 64 --device mps --workers 8
```

Weights land in `runs/classify/plantvillage_yolo26n_cls/weights/best.pt`.

## 5. Run the webcam

```bash
./.venv/bin/python webcam.py
```

`webcam.py` picks the newest checkpoint under `runs/`, selects `mps`, and opens the
preview. Press `q` to quit. For explicit control:

```bash
./.venv/bin/leaf-realtime \
  --classifier runs/classify/plantvillage_yolo26n_cls/weights/best.pt \
  --source 0 --device mps
```

Record the session instead of previewing it:

```bash
./.venv/bin/leaf-realtime --classifier runs/classify/plantvillage_yolo26n_cls/weights/best.pt \
  --source 0 --device mps --no-view --save runs/webcam.mp4
```

## Analysing uploaded photos

A photo can be framed properly, which beats holding a leaf in front of a laptop. Same
model, plus treatment guidance for every class:

```bash
./.venv/bin/leaf-analyze photo.jpg
./.venv/bin/leaf-analyze photos/ --out reports/ --json report.json
```

Output per finding: diagnosis, confidence, runner-up classes, the pathogen, and what to do
about it. Findings are marked `[!!]` when a slow response loses the crop -- late blight,
citrus greening, the whitefly-borne viruses -- and `[ok]` when nothing needs doing.

`--out` writes annotated copies with boxes drawn; `--json` writes the full structured
report for anything downstream. With a detector checkpoint present, each leaf in the photo
is found and diagnosed separately; without one the whole image is treated as a single leaf.

Treatment guidance lives in `src/leaf_ai/advice.py`. It is general agronomic practice --
approved products and notification rules vary by country, and citrus greening is
notifiable in many regions.

## Datasets

| Dataset | Rows | What it is | Used for |
|---|---|---|---|
| PlantVillage | 54,381 | detached leaves, plain background, studio light | classifier |
| COCO negatives | 3,100 | people, rooms, objects | the `Not_a_leaf` class |
| PlantDoc | 2,574 | field photos with bounding boxes | detector |
| PlantWild v2 | 18,542 | in-the-wild disease photos, 115 classes | classifier (in-the-wild) |

```bash
./.venv/bin/leaf-download-plantvillage-hf --out data/processed/plantvillage_cls
./.venv/bin/leaf-download-negatives --overwrite
./.venv/bin/leaf-download-plantdoc-hf --overwrite     # no Roboflow key needed
```

PlantDoc and PlantVillage are permissively licensed. **PlantWild v2 is CC-BY-NC-ND-4.0**:
non-commercial, no derivatives. Fine for personal and educational work, but a model
trained on it cannot be shipped commercially.

## Why it does not call your face a peach leaf

PlantVillage is a closed set. Every image in it is a leaf, so a model trained on it alone
cannot answer "that is not a leaf" -- softmax spreads 100% across the plant classes no
matter what the camera sees. Pointed at a person it will pick the nearest plant and look
confident doing it. Two independent guards handle this.

**1. Vegetation gate (heuristic, always on).** Before the classifier runs, the centre crop
is scored with an excess-green index, `2G - R - B` on channel-normalised pixels. Foliage
has more green than red; skin, wood and walls have more red than green. Measured scores:

| Input | Score | Result |
|---|---|---|
| Tomato late blight leaf | 0.34 | classified |
| Apple healthy leaf | 0.42 | classified |
| Citrus greening (brown/yellow leaf) | 0.56 | classified |
| Skin tone | 0.00 | rejected |
| Grey wall | 0.00 | rejected |
| Blue shirt | 0.00 | rejected |

Below `--min-leaf` (default 0.05) the overlay reads **no leaf in view** and no disease
label is drawn. Raise it to reject more aggressively, or pass `--min-leaf 0` to disable.

The live score is always drawn under the crop box as `veg 0.42`, so you can tune against
real numbers rather than guessing. Note it is a ratio, not a brightness measure -- a badly
underexposed leaf still scores around 0.8.

## Reading the overlay when nothing is identified

Three different things can suppress a diagnosis, and each says so explicitly:

| Overlay text | Meaning | What to change |
|---|---|---|
| `no leaf in view (veg 0.04 < 0.05)` | the heuristic gate rejected the crop | lower `--min-leaf`, or fill the box with the leaf |
| `model says: not a leaf (92%)` | the trained `Not_a_leaf` class fired | genuine reject, or the model is undertrained |
| `too close to call (margin 0.08)` | top two classes are near-tied | lower `--min-margin` to accept weaker calls |

If everything reads `model says: not a leaf`, check you are not running a half-trained
checkpoint. `webcam.py` prefers runs that completed every configured epoch and prints a
warning when it has to fall back to an in-progress one.

**2. `Not_a_leaf` class (trained).** The dataset carries a 39th class built from COCO
photos -- people, rooms, furniture, street scenes -- so the model has a real reject option
rather than relying on the heuristic alone:

```bash
./.venv/bin/leaf-download-negatives --overwrite
./.venv/bin/leaf-train classify --config configs/training/classify_plantvillage.yaml \
  --name plantvillage_yolo26n_cls_39 --epochs 8 --batch 64 --device mps
```

COCO images that are themselves mostly foliage are skipped (`--max-vegetation`, default
0.35) so the reject class never teaches the model that green plant matter is background.

**3. Margin check.** If the top two classes are within `--min-margin` (default 0.15) of
each other, the frame is reported as unsure rather than committed to a diagnosis.

## Accuracy caveat worth knowing

The classifier knows 14 crop species and nothing else: apple, blueberry, cherry, corn,
grape, orange, peach, bell pepper, potato, raspberry, soybean, squash, strawberry, tomato.
A houseplant, a fern or a tree leaf outside that list cannot be classified correctly -- the
right outcome there is `Not_a_leaf` or "no leaf in view", not a confident wrong answer.
Widening species coverage needs an additional dataset, not more PlantVillage.

### Distribution gap

PlantVillage images are single detached leaves on a plain background under even lighting.
A model trained only on it is accurate on that distribution and noticeably weaker on a
leaf still attached to a plant, on a cluttered background, or in uneven light. The
vegetation gate and the `Not_a_leaf` class stop it inventing a diagnosis for a non-leaf,
but they do not make it accurate on a hard leaf shot -- expect lower confidence there.

Two ways to improve real-world behaviour, in order of effort:

1. Fill the centre box with a single leaf against a plain background. This matches the
   training distribution and is the difference between a demo that works and one that
   does not.
2. Add the detector branch so leaves are located before classification. That needs
   PlantDoc, which is field-photo data with bounding boxes, and a Roboflow API key:
   `leaf-download-plantdoc --out data/raw/plantdoc` then
   `leaf-train detect --config configs/training/detect_plantdoc.yaml`. Once
   `runs/detect/*/weights/best.pt` exists, `webcam.py` picks it up automatically and
   switches to detect-then-classify.

## Differences from the PowerShell README

| README (Windows) | macOS |
|---|---|
| `.\.venv\Scripts\Activate.ps1` | `source .venv/bin/activate` |
| `--device 0` (CUDA) | `--device mps` |
| `batch: -1` AutoBatch | explicit `--batch 64` |
| Kaggle credentials for PlantVillage | `leaf-download-plantvillage-hf`, no account |
| TensorRT `--format engine` | not available; use `--format onnx` or `coreml` |

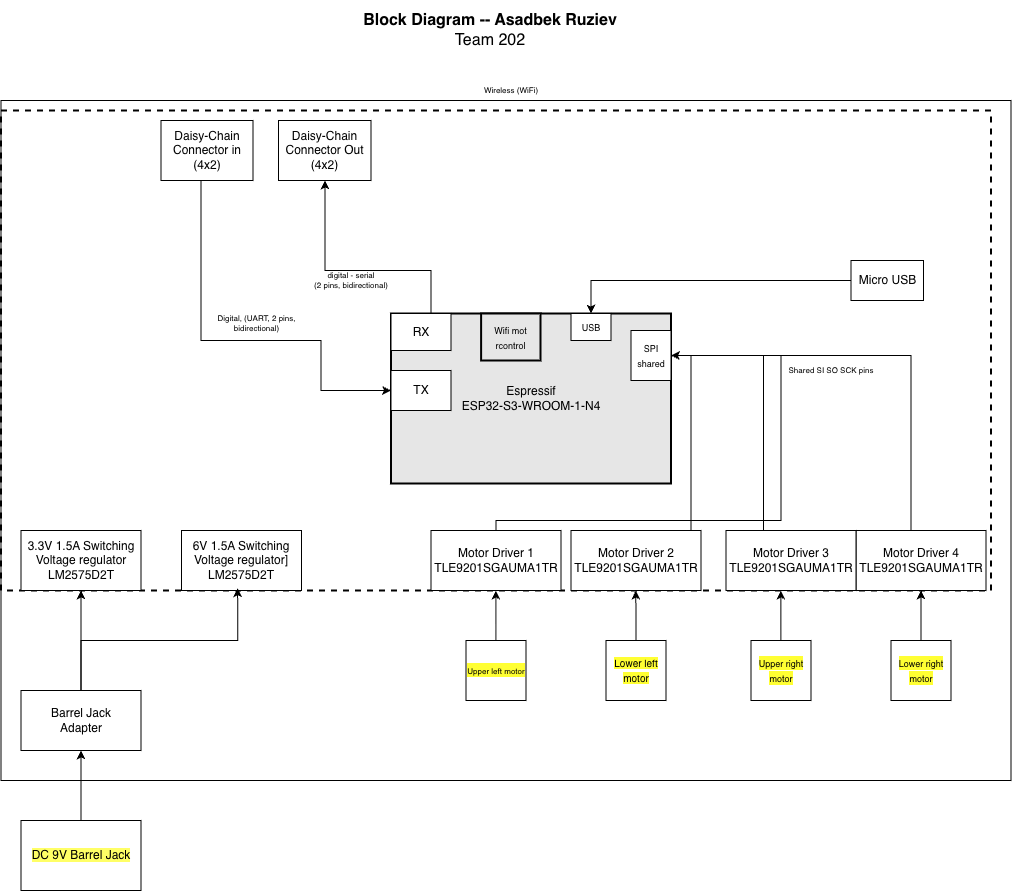
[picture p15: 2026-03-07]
docs/02-Block-Diagram/blockv1.drawio.png

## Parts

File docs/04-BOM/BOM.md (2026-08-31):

  
**Overview**  
**Half of the items below will be ordered from Digikey, and the other half is available from the Peralta labs.** 

**The total would be around $47.98**

Table 1: Mobility Subsystem Bill of Materials

| Part name | Quantity | Unit cost | Total cost | Manufacturer | Manufacturer \# | Supplier | Vendor link | Link to the datasheet | Reference for the schematic |
| :---- | :---- | :---- | :---- | :---- | :---- | :---- | :---- | :---- | :---- |
| 330uF | 1 | 0.85 | 0.85 | Panasonic Electronic Components | PCE3803TR-ND | Digikey | [Link](https://www.digikey.com/en/products/detail/panasonic-electronic-components/EEE-FK1E331P/765972) | [Link](https://industrial.panasonic.com/cdbs/www-data/pdf/RDE0000/ABA0000C1181.pdf) | C1 |
| 100uF | 1 | 0.93 | 0.93 | Panasonic Electronic Components | PCE5024TR-ND | Digikey | [Link](https://www.digikey.com/en/products/detail/panasonic-electronic-components/EEE-FTH101XAP/2652055) | [Link](https://industrial.panasonic.com/cdbs/www-data/pdf/RDE0000/ABA0000C1240.pdf) | C2 |
| 1uF | 1 | $0.12 | 0.12 | EEE-FTH101XAP | PCE5024TR-ND | Digikey | [Link](https://www.digikey.com/en/products/detail/kemet/C0805C105K3RACTU/2211765) | [Link](https://yageogroup.com/content/datasheet/asset/file/KEM_C1002_X7R_SMD) | C3 |
| 0.1 uF 50 V | 1 | 0.08 | 0.08 | KEMET | 399-C0805C104K5RACTUTR-ND | Digikey | [Link](https://www.digikey.com/en/products/detail/kemet/C0805C104K5RACTU/411169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) | [Link](https://yageogroup.com/content/datasheet/asset/file/KEM_C1002_X7R_SMD) | C4 |
| 1 uF 50V | 1 | $0.12 | 0.12 | EEE-FTH101XAP | PCE5024TR-ND | Digikey | [Link](https://www.digikey.com/en/products/detail/kemet/C0805C105K3RACTU/2211765) | [Link](https://yageogroup.com/content/datasheet/asset/file/KEM_C1002_X7R_SMD) | C5 |
| 1N5819 | 1 | 0.34 | 0.34 | STMicroelectronics | 497-6610-1-ND | Digikey | [Link](https://www.digikey.com/en/products/detail/stmicroelectronics/1N5819/1037326) | [Link](https://www.st.com/content/ccc/resource/technical/document/datasheet/26/db/14/60/52/47/47/5b/CD00001625.pdf/files/CD00001625.pdf/jcr:content/translations/en.CD000016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) | D1 |
| LED | 2 | 0.71 | 1.52 | Visual Communications Company \- VCC | L62501TR-ND | Digikey | [Link](https://www.digikey.com/en/products/detail/visual-communications-company-vcc/CMD17-21VRD-TR8/254853) | [Link](https://mm.digikey.com/Volume0/opasdata/d220001/medias/docus/4320/CMD17-21_Rev10.pdf) | D2,D3 |
| 1N4148WT | 1 | 0.11 | 0.11 | onsemi | 1N4148WTTR-ND | Digikey | [Link](https://www.digikey.com/en/products/detail/onsemi/1N4148WT/1954014) | [Link](https://mm.digikey.com/Volume0/opasdata/d220001/medias/docus/6621/1N914BWTCND.pdf) | D4 |
| Fuse | 2 | 0.57 | 1.14 | SCHURTER Inc. | 486-1794-ND | Digikey | [Link](https://www.digikey.com/en/products/detail/schurter-inc/0034-1515/639670) | [Link](https://www.schurter.com/en/datasheet/typ_FSF_5x20.pdf) | F1,F2 |
| Barrel\_Jack\_Switch | 1 | 0.71 | 0.71 | Same Sky (Formerly CUI Devices) | CP-102AH-ND | Digikey | [Link](https://www.digikey.com/en/products/detail/same-sky-formerly-cui-devices/PJ-102AH/408448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) | [Link](https://www.sameskydevices.com/product/resource/pj-102ah.pdf) | J1 |
| Connector In | 1 | 0.99 | 0.99 | Würth Elektronik | 732-5395-ND | Digikey | [Link](https://www.digikey.com/en/products/detail/w%C3%BCrth-elektronik/61200821621/4846916) | [Link](https://www.we-online.com/components/products/datasheet/61200821621.pdf) | J2 |
| Connector Out | 1 | 0.99 | 0.99 | Würth Elektronik | 732-5395-ND | Digikey | [Link](https://www.digikey.com/en/products/detail/w%C3%BCrth-elektronik/61200821621/4846916) | [Link](https://www.we-online.com/components/products/datasheet/61200821621.pdf) | J3 |
| Left motors | 2 | 2.95 | 5.9 | Geartisan | 766330627149 | Amazon | [Link](https://a.co/d/0cYP6F4E) | [Link](https://a.co/d/0cYP6F4E) | J4,J5 |
| Right motors | 2 | 2.95 | 5.9 | Greartisan | 766330627149 | Amazon | [Link](https://a.co/d/0cYP6F4E) | [Link](https://a.co/d/0cYP6F4E) | J6,J7 |
| 9V battery header | 1 | 2.50 | 2.50 | Bud Industries | 377-2053-ND | Digikey | [Link](https://www.digikey.com/en/products/detail/bud-industries/HH-3634/3681242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) | [Link](https://www.budind.com/wp-content/uploads/2019/12/hb3634.pdf) | J8 |
| USB\_B\_Micro | 1 | 0.78 | 0.78 | GCT | 2073-USB3131-30-0230-ACT-ND | Digikey | [Link](https://www.digikey.com/en/products/detail/gct/USB3131-30-0230-A/9859642) | [Link](https://gct.co/files/specs/usb3131-spec.pdf) | J9 |
| 220uH | 1 | 0.50 | 0.50 | Murata Power Solutions Inc. | 811-1159-2-ND | Digikey | [Link](http://embedded-systems-design.bitbucket.io/314/labs/switching-power-supply/) | [Link](https://www.bourns.com/docs/Product-Datasheets/RLB9012.pdf) | L1 |
| 10K | 2 | 0.10 | 0.20 | Stackpole Electronics Inc | 738-RMCF1206JG10K0TR-ND | Digikey | [Link](https://www.digikey.com/en/products/detail/stackpole-electronics-inc/RMCF1206JG10K0/21720266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) | [Link](https://www.seielect.com/catalog/SEI-RMCF_RMCP.pdf) | R1,R2 |
| 10k | 2 | 0.10 | 0.20 | Stackpole Electronics Inc | 738-RMCF1206JG10K0TR-ND | Digikey | [Link](https://www.digikey.com/en/products/detail/stackpole-electronics-inc/RMCF1206JG10K0/21720266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) | [Link](https://www.seielect.com/catalog/SEI-RMCF_RMCP.pdf) | R3,R5 |
| SW\_Push | 2 | 0.90 | 1.80 | Omron Electronics Inc-EMC Div | SWITCH TACTILE SPST-NO 0.05A 12V | Digikey | [Link](https://www.digikey.com/en/products/detail/omron-electronics-inc-emc-div/B3U-1000P/1534338) | [Link](https://omronfs.omron.com/en_US/ecb/products/pdf/en-b3u.pdf) | SW1,SW2 |
| Motor driver | 4 | 3.77 | 15.08 | Infineon Technologies | TLE9201SGAUMA1TR-ND | Digikey | [Link](https://www.digikey.com/en/products/detail/infineon-technologies/TLE9201SGAUMA1/5960696) | [Link](https://www.infineon.com/assets/row/public/documents/10/49/infineon-tle9201sg-ds-en.pdf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) | TLE9201SG1\_1,TLE9201SG1\_2,TLE9201SG1\_3,TLE9201SG1\_4 |
| TestPoint | 4 |  |  |  |  |  |  |  | TP1,TP2,TP3,TP4 |
| LM2575D2T-3.3R4G | 1 | 2.16 | 2.16 | onsemi | LM2575D2T-3.3R4GOSTR-ND | Digikey | [Link](https://www.digikey.com/en/products/detail/onsemi/LM2575D2T-3-3R4G/1476688) | [Link](https://www.onsemi.com/pdf/datasheet/lm2575-d.pdf) | U3 |
| ESP32-S3-WROOM-1 | 1 | 5.06 | 5.06 | Espressif systems | ESP32-S3-WROOM-1-N4 | Digikey | [Link](https://www.digikey.com/en/products/detail/espressif-systems/ESP32-S3-WROOM-1-N4/16162639)  | [Link](https://documentation.espressif.com/esp32-s3-wroom-1_wroom-1u_datasheet_en.pdf) | U5 |

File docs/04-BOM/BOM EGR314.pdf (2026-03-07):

## Overview

Half of the items below will be ordered from Digikey, and the other half is available from the Peralta labs.

The total would be around

Table 1: Mobility Subsystem Bill of Materials
Part name | Qua ntity | Unit cost | Total cost | Manufact urer | Manufacturer # | Supplie r | Ven dor link | Link to the datash eet | Refer ence for the sche matic
330uF | 1 | 0.85 | 0.85 | Panasonic Electronic Compone nts | PCE3803TR-ND | Digikey | Link (https://www.digikey.com/en/products/detail/panasonic-electronic-components/EEE-FK1E331P/765972) | Link (https://industrial.panasonic.com/cdbs/www-data/pdf/RDE0000/ABA0000C1181.pdf) | C1
100uF | 1 | 0.93 | 0.93 | Panasonic Electronic Compone nts | PCE5024TR-ND | Digikey | Link (https://www.digikey.com/en/products/detail/panasonic-electronic-components/EEE-FTH101XAP/2652055) | Link (https://industrial.panasonic.com/cdbs/www-data/pdf/RDE0000/ABA0000C1240.pdf) | C2
1uF | 1 | $0.12 | 0.12 | EEE-FTH 101XAP | PCE5024TR-ND | Digikey | Link (https://www.digikey.com/en/products/detail/kemet/C0805C105K3RACTU/2211765) | Link (https://yageogroup.com/content/datasheet/asset/file/KEM_C1002_X7R_SMD) | C3
0.1 uF 50 V | 1 | 0.08 | 0.08 | KEMET | 399-C0805C104K5 RACTUTR-ND | Digikey | Link (https://www.digikey.com/en/products/detail/kemet/C0805C104K5RACTU/411169) | Link (https://yageogroup.com/content/datasheet/asset/file/KEM_C1002_X7R_SMD) | C4
1 uF 50V | 1 | $0.12 | 0.12 | EEE-FTH 101XAP | PCE5024TR-ND | Digikey | Link (https://www.digikey.com/en/products/detail/kemet/C0805C105K3RACTU/2211765) | Link (https://yageogroup.com/content/datasheet/asset/file/KEM_C1002_X7R_SMD) | C5
1N5819 | 1 | 0.34 | 0.34 | STMicroel ectronics | 497-6610-1-ND | Digikey | Link (https://www.digikey.com/en/products/detail/stmicroelectronics/1N5819/1037326) | Link (https://www.st.com/content/ccc/resource/technical/document/datasheet/26/db/14/60/52/47/47/5b/CD00001625.pdf/files/CD00001625.pdf/jcr:content/translations/en.C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) | D1
LED | 2 | 0.71 | 1.52 | Visual Communi cations Company - VCC | L62501TR-ND | Digikey | Link (https://www.digikey.com/en/products/detail/visual-communications-company-vcc/CMD17-21VRD-TR8/254853) | Link (https://mm.digikey.com/Volume0/opasdata/d220001/medias/docus/4320/CMD17-21_Rev10.pdf) | D2,D3
1N4148WT | 1 | 0.11 | 0.11 | onsemi | 1N4148WTTR-ND | Digikey | Link (https://www.digikey.com/en/products/detail/onsemi/1N4148WT/1954014) | Link (https://mm.digikey.com/Volume0/opasdata/d220001/medias/docus/6621/1N914BWTCND.pdf) | D4
Fuse | 2 | 0.57 | 1.14 | SCHURT ER Inc. | 486-1794-ND | Digikey | Link (https://www.digikey.com/en/products/detail/schurter-inc/0034-1515/639670) | Link (https://www.schurter.com/en/datasheet/typ_FSF_5x20.pdf) | F1,F2
Barrel_Jack_Switch | 1 | 0.71 | 0.71 | Same Sky | CP-102AH-ND | Digikey | Link (https://www.digikey.com/en/products/detail/same-sky-formerly-cui-devices/PJ-102AH/408448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) | Link (https://www.sameskydevices.com/product/resource/pj-102ah.pdf) | J1

| | | | (Formerly CUI Devices)
Connector In | 1 | 0.99 | 0.99 | Würth Elektronik | 732-5395-ND | Digikey | Link (https://www.digikey.com/en/products/detail/w%C3%BCrth-elektronik/61200821621/4846916) | Link (https://www.we-online.com/components/products/datasheet/61200821621.pdf) | J2
Connector Out | 1 | 0.99 | 0.99 | Würth Elektronik | 732-5395-ND | Digikey | Link (https://www.digikey.com/en/products/detail/w%C3%BCrth-elektronik/61200821621/4846916) | Link (https://www.we-online.com/components/products/datasheet/61200821621.pdf) | J3
Left motors | 2 | 2.95 | 5.9 | Adafruit Industries LLC | 1528-2589-ND | Digikey | Link (https://www.digikey.com/en/products/detail/adafruit-industries-llc/3777/8687221) | Link (https://mm.digikey.com/Volume0/opasdata/d220001/medias/docus/713/3777_Web.pdf) | J4,J5
Right motors | 2 | 2.95 | 5.9 | Adafruit Industries LLC | 1528-2589-ND | Digikey | Link (https://www.digikey.com/en/products/detail/adafruit-industries-llc/3777/8687221) | Link (https://mm.digikey.com/Volume0/opasdata/d220001/medias/docus/713/3777_Web.pdf) | J6,J7
9V battery header | 1 | 2.50 | 2.50 | Bud Industries | 377-2053-ND | Digikey | Link (https://www.digikey.com/en/products/detail/bud-industries/HH-3634/3681242?gclsrc=aw.ds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) | Link (https://www.budind.com/wp-content/uploads/2019/12/hb3634.pdf) | J8
USB_B_Micro | 1 | 0.78 | 0.78 | GCT | 2073-USB3131-3 0-0230-ACT-ND | Digikey | Link (https://www.digikey.com/en/products/detail/gct/USB3131-30-0230-A/9859642) | Link (https://gct.co/files/specs/usb3131-spec.pdf) | J9
220uH | 1 | 0.50 | 0.50 | Murata Power Solutions Inc. | 811-1159-2-ND | Digikey | Link (http://embedded-systems-design.bitbucket.io/314/labs/switching-power-supply/) | Link (https://www.bourns.com/docs/Product-Datasheets/RLB9012.pdf) | L1
10K | 2 | 0.10 | 0.20 | Stackpole Electronic s Inc | 738-RMCF1206JG 10K0TR-ND | Digikey | Link (https://www.digikey.com/en/products/detail/stackpole-electronics-inc/RMCF1206JG10K0/21720266?gclsrc=aw.ds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) | Link (https://www.seielect.com/catalog/SEI-RMCF_RMCP.pdf) | R1,R2
10k | 2 | 0.10 | 0.20 | Stackpole Electronic s Inc | 738-RMCF1206JG 10K0TR-ND | Digikey | Link (https://www.digikey.com/en/products/detail/stackpole-electronics-inc/RMCF1206JG10K0/21720266?gclsrc=aw.ds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) | Link (https://www.seielect.com/catalog/SEI-RMCF_RMCP.pdf) | R3,R5
SW_Push | 2 | 0.90 | 1.80 | Omron Electronic s Inc-EMC Div | SWITCH TACTILE SPST-NO 0.05A 12V | Digikey | Link (https://www.digikey.com/en/products/detail/omron-electronics-inc-emc-div/B3U-1000P/1534338) | Link (https://omronfs.omron.com/en_US/ecb/products/pdf/en-b3u.pdf) | SW1,SW 2
Motor driver | 4 | 3.77 | 15.08 | Infineon Technolog ies | TLE9201SGAUMA 1TR-ND | Digikey | Link (https://www.digikey.com/en/products/detail/infineon-technologies/TLE9201SGAUMA1/5960696) | Link (https://www.infineon.com/assets/row/public/documents/10/49/infineon-tle9201sg-ds-en.pdf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) | TLE9201 SG1_1,T LE9201S G1_2,TL E9201SG 1_3,TLE9 201SG1_ 4
TestPoint | 4 | | | | | | | | TP1,TP2, TP3,TP4
LM2575D2T-3.3R4 G | 1 | 2.16 | 2.16 | onsemi | LM2575D2T-3.3R4 | Digikey | Link (https://www.digikey.com/en/products/detail/onsemi/LM2575D2T-3-3R4G/1476688) | Link (https://www.onsemi.com/pdf/datasheet/lm2575-d.pdf) | U3

| | | | | G O S T R -N D
ESP32-S3-WROO M-1 | 1 | 5.0 6 | 5.0 6 | E s p r e s sif s y s t e m s | E S P 3 2 -S 3 -W R O O M -1 -N 4 | Digik e y | Lin k (https://www.digikey.com/en/products/detail/espressif-systems/ESP32-S3-WROOM-1-N4/16162639) | Lin k (https://documentation.espressif.com/esp32-s3-wroom-1_wroom-1u_datasheet_en.pdf) | U5

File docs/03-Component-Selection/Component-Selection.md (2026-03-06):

**Module’ selected major components:**

**Motors:**   
I have decided to choose the 2nd option because it is relatively cheap compared to the first. Apart from that, a gearmotor can work with a lower voltage. I have used this motor on many of my projects, and it has never caused issues.

| Component | Pros | Cons |
| :---- | :---- | :---- |
| [FIT0489-D Gearmotor 40 RPM 12V turbo metal](https://www.digikey.com/en/products/detail/dfrobot/FIT0489-D/7087173) Price: $18.9  | Works on hard surfaces Very nice torque for high load Low power consumption | Very costly Heavier than most gearmotors and has very low RPM Need more power and hard to work with surface mount motor drivers |
| [Adafruit Gearmotor 200 RPM 3-6V DC](https://www.digikey.com/en/products/detail/adafruit-industries-llc/3777/8687221)  Price: $2.95 | Has high RPM Has special holes for mounting to the rover wheel Works well with lower voltage levels. | Can’t always handle high load  |
| [1528-2607-ND](https://www.digikey.com/en/products/detail/adafruit-industries-llc/3801/9342522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) GEARMOTOR 120 RPM 3-6V BI-METAL Price: $4.5  | Bi-metal gearbox Stronger than a simple gear motor Good price for its usage | Low RPM Bit costly |

**3.3 buck voltage regulator**  
**Final selection: LM2575**  
**Rationale:** 

| Component | Pros | Cons |
| :---- | :---- | :---- |
| **[LM2575D2T-3.3R4G](https://www.digikey.com/en/products/detail/onsemi/LM2575D2T-3-3R4G/1476688)** Price: $2.16 **** | Very clear datasheet Good cost Up to 40V input voltage | Has issues with Amperage Higher cost |
| [AP63203WU-7](https://www.digikey.com/en/products/detail/diodes-incorporated/AP63203WU-7/9858426)  Price: $0.71 | Wide input range 2A output current Protection inside from thermal shutdown | Noise of the switch |
| [UA78M33CDCY](https://www.digikey.com/en/products/detail/texas-instruments/UA78M33CDCY/1910312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) Price: $1.07 | Low cost Only input and output needed  | Low efficiency with more than 6V supply |
| [LM2596S-3.3-ND](https://www.digikey.com/en/products/detail/texas-instruments/LM2596S-3-3/3701219) Price: $8.76  | Works well with 3A Input voltage operation up to 40 V Simple design for soldering | Fixed at 150 kHz Too costly for my subsystem |

**Motor driver.** This motor driver will be used to make 4 of my motors move in different directions and to help control their speed. I am going to choose the 2nd option for my motor driver.

| Component | Pros | Cons |
| :---- | :---- | :---- |
| [BH6766FVM-GTR](https://www.digikey.com/en/products/detail/rohm-semiconductor/BH6766FVM-GTR/7895655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) Price: $1.02  | Suitable for small systems |  |
|  [TLE9201SGAUMA1TR-ND](https://www.digikey.com/en/products/detail/infineon-technologies/TLE9201SGAUMA1/5960696) Price: $3.77  | Can use 2 motors Speed control with enable 1 and enable 2 | Very high cost compared to the other 2 options |
| [IFX9201SGAUMA1](https://www.digikey.com/en/products/detail/infineon-technologies/IFX9201SGAUMA1/5415542) Price: $3.55   | Simple design Short circuit protection | Careful PCB layout Higher cost than many motor drivers Two devices would be required, so a bigger PCB space is needed |

**Notes:** All parts are from Digikey or other reliable part providers to ensure compatibility and availability of datasheet.

[image1]: <>

[image2]: <>

[image3]: <>

[image4]: <>

[image5]: <>

[image6]: <>

[image7]: <>

[image8]: <>

[image9]: <>

[image10]: <>

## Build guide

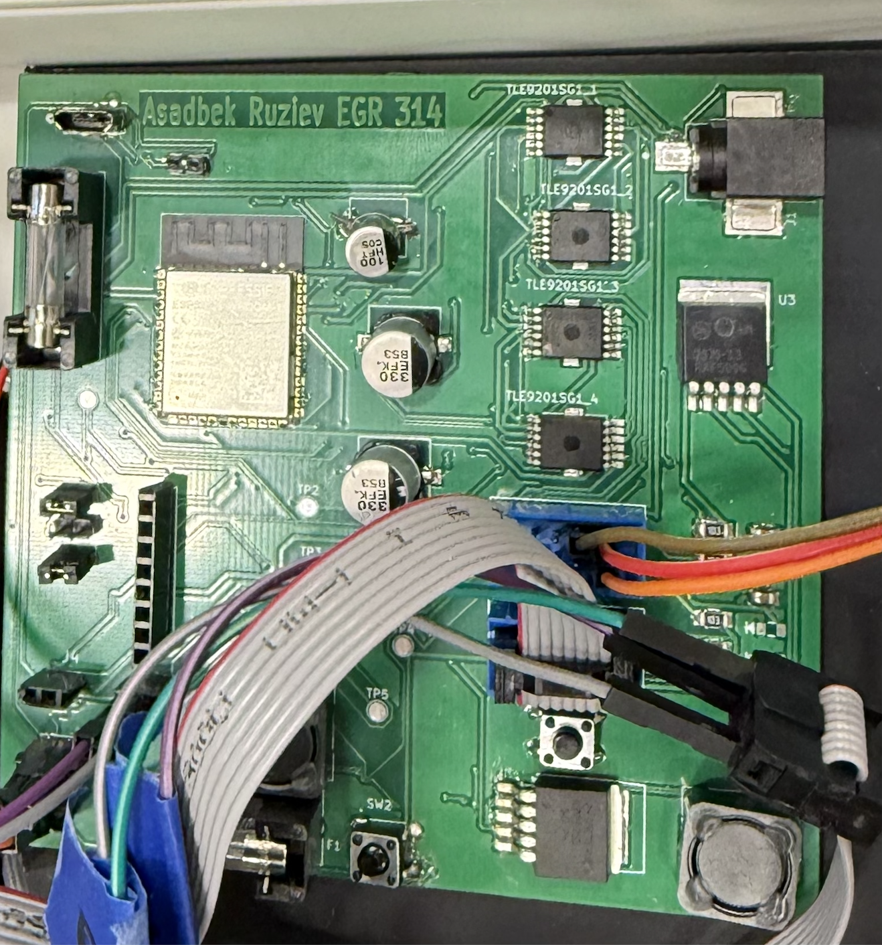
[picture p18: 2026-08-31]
docs/06-PCB/soldered.png

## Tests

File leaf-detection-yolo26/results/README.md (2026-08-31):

# Training results

Metrics and curves from the runs in this repo, copied out of `runs/`
(which is gitignored — it holds 85 MB of checkpoints and per-epoch images).

Each folder has:

- `args.yaml` — the exact hyperparameters the run used
- `results.csv` — per-epoch loss and accuracy
- `results.png` — the training curves
- `confusion_matrix_normalized.png` — per-class performance (classification runs)

| Run | Task |
|-----|---|
| `plantvillage_yolo26n_cls_39` | YOLO26-n classification, 39 PlantVillage classes |
| `plantvillage_plantwild_cls` | classification on PlantVillage + PlantWild merged |
| `plantvillage_yolo26n_cls` | first classification baseline |
| `plantdoc_yolo26n` | YOLO26-n detection on PlantDoc |

Delete this folder if you'd rather keep the repo source-only.

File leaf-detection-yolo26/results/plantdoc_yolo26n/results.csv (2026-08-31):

epoch | time | train/box_loss | train/cls_loss | train/l1_loss | metrics/precision(B) | metrics/recall(B) | metrics/mAP50(B) | metrics/mAP50-95(B) | val/box_loss | val/cls_loss | val/l1_loss | lr/pg0 | lr/pg1 | lr/pg2
1 | 275.442 | 1.21419 | 5.48255 | 0.01328 | 0.01046 | 0.72092 | 0.04639 | 0.0364 | 0.82493 | 7.51454 | 0.01785 | 0.000100313 | 0.000100313 | 0.000100313
2 | 512.21 | 1.17152 | 4.84118 | 0.01278 | 0.56176 | 0.11264 | 0.11373 | 0.08842 | 0.85534 | 6.64041 | 0.01891 | 0.00019633 | 0.00019633 | 0.00019633
3 | 1661.38 | 1.20864 | 4.27235 | 0.01364 | 0.41434 | 0.21463 | 0.2033 | 0.15725 | 0.95014 | 5.77679 | 0.0223 | 0.000287348 | 0.000287348 | 0.000287348
4 | 2834.7 | 1.22661 | 3.85832 | 0.01387 | 0.31962 | 0.32393 | 0.28944 | 0.22827 | 0.95465 | 5.22469 | 0.02144 | 0.000280502 | 0.000280502 | 0.000280502
5 | 3563.26 | 1.23499 | 3.5329 | 0.01361 | 0.3106 | 0.34685 | 0.32585 | 0.2613 | 0.92707 | 4.59093 | 0.02078 | 0.000273003 | 0.000273003 | 0.000273003
6 | 3823.95 | 1.21491 | 3.28508 | 0.0136 | 0.37943 | 0.42086 | 0.38273 | 0.29906 | 0.94639 | 4.2916 | 0.02122 | 0.000265504 | 0.000265504 | 0.000265504
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

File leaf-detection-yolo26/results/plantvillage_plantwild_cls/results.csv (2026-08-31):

epoch | time | train/loss | metrics/accuracy_top1 | metrics/accuracy_top5 | val/loss | lr/pg0 | lr/pg1 | lr/pg2
1 | 439.563 | 3.08903 | 0.71354 | 0.865 | 1.29122 | 2.93009e-05 | 2.93009e-05 | 2.93009e-05
2 | 465.985 | 1.03263 | 0.85854 | 0.94615 | 0.54214 | 5.13996e-05 | 5.13996e-05 | 5.13996e-05
3 | 935.211 | 0.64527 | 0.88758 | 0.97026 | 0.39565 | 6.62139e-05 | 6.62139e-05 | 6.62139e-05
4 | 1394.63 | 0.51142 | 0.9078 | 0.97881 | 0.32628 | 5.533e-05 | 5.533e-05 | 5.533e-05
5 | 1863.52 | 0.44159 | 0.91426 | 0.98103 | 0.30093 | 4.444e-05 | 4.444e-05 | 4.444e-05
6 | 2342.33 | 0.40327 | 0.92003 | 0.98312 | 0.28001 | 3.355e-05 | 3.355e-05 | 3.355e-05
7 | 2801.34 | 0.3724 | 0.92239 | 0.98333 | 0.26788 | 2.266e-05 | 2.266e-05 | 2.266e-05
8 | 3437.7 | 0.35743 | 0.92392 | 0.98388 | 0.26326 | 1.177e-05 | 1.177e-05 | 1.177e-05

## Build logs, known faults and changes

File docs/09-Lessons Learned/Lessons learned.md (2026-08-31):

---
title: Module Lessons
---

### Overview

## Module success 
Our project was successful, with most of our planned project requirements being met. We were able to move the wheels, the 3DoF front arm, get temperature and humidity readings, as well as the metal detector. While there were some issues during the daisy chain, our project worked most of the time. The rover was working well for 5 hours during the Innovation Showcase, and there was nothing that blew up.

## Lessons learned

1. I learned that UART TX0 and RX0 are not the best pins for the UART connection, and this caused many issues with my motor's movement, as my motors move freely without the daisy chain, but when I receive commands from HMI through MQTT, my motor faces issues by being locked up.

2. I learned a lot about the importance of showing up to classes and team meetings and being able to take notes.

3. I learned importance of starting to work on PCB early, as well as double and triple checking PCB design, was very important for me, but I started working on my PCB 2 days before the deadline, so it is a big lesson for me for future projects.

4. I learned to order components early and coordinate with your teammates and professor to choose good motors if you are running 4 wheels. We ordered wheels from Amazon, and they were not delivered on time, even though the planned delivery date was before the Innovation Showcase.

5. I learned that I need to spend enough time outside of this class. Make sure to attend meetings and come to every class on time. Participation and communication in team meetings are highly important and valuable, helping you stay on track to complete tasks and finish the subsystem.

6. 3D printing or machining your design/frame to include your PCBs and electronics would be very professional and helpful to showcase your concept design more clearly.

7. I learned importance of starting to work on PCB early, as well as double and triple checking PCB design, was very important for me, but I started working on my PCB 2 days before the deadline, so it is a big lesson for me for future projects.

8. Learning coding on Python and VS Code and reviewing slides from EGR 219 is crucial. This class is very coding-heavy and those skills are crucial for the career too.

9. I learned that putting components in proper way on the PCB is crucial. I put my barrel jack right next to my voltage regulator and it was hard to connect wires.

10. It is important to update the datasheet website as you go. Try to write changes to the website as you go. This helps to keep up with assignments and to keep up with the design review.

## Recommendations for future students

1. Read the lab manual and resources for the lab thoroughly. The links provided to you are very helpful to get started on working with your subsystem. Try to read at least part of a website every day, since they have helpful information you need, like voltage regulators, ESP32 setup, MQTT, timers, sensors, etc.

2. Start labs early. This would be very helpful as you would have an idea of what you are doing instead of rushing through getting checked off. 

3. Asks questions from TAs and attends office hours. TAs have taken this class, and they have troubleshooted issues with their PCB and coding, so get feedback from them.

4. Make sure to include twice more components from Digikey than you actually need for your PCB. You might need to resolder few components for your PCB and having extra parts like LEDs, buttons, motor drivers is crucial.

5. Learn surface mount soldering by practising on cheap boards from Amazon. That way you will be well prepapred before your PCB arrives.

## Microcontroller/Module Startup Tip
I would suggest uploading MicroPython to your ESP32 before connecting and programming. This would troubleshoot any potential issues you might face when connecting to your ESP32.

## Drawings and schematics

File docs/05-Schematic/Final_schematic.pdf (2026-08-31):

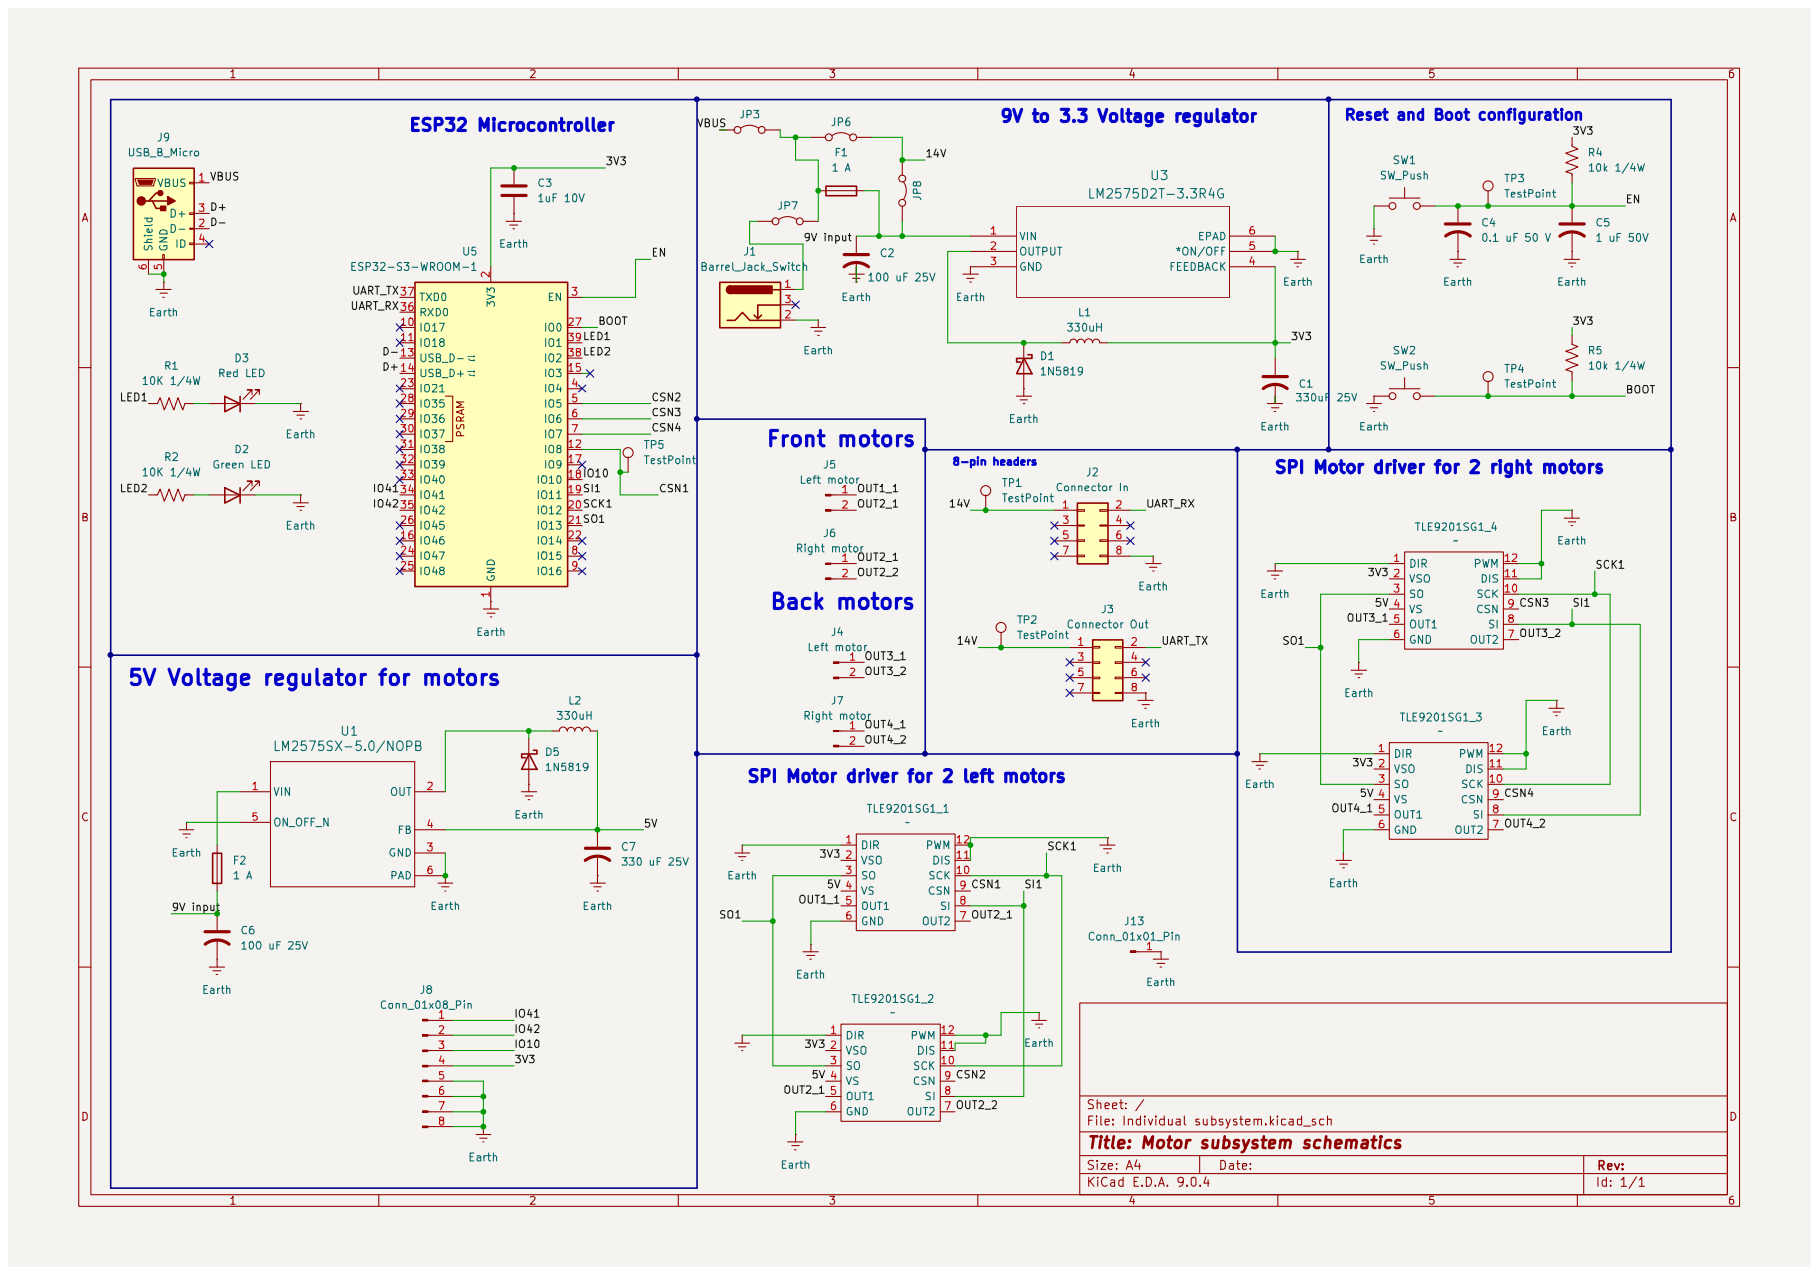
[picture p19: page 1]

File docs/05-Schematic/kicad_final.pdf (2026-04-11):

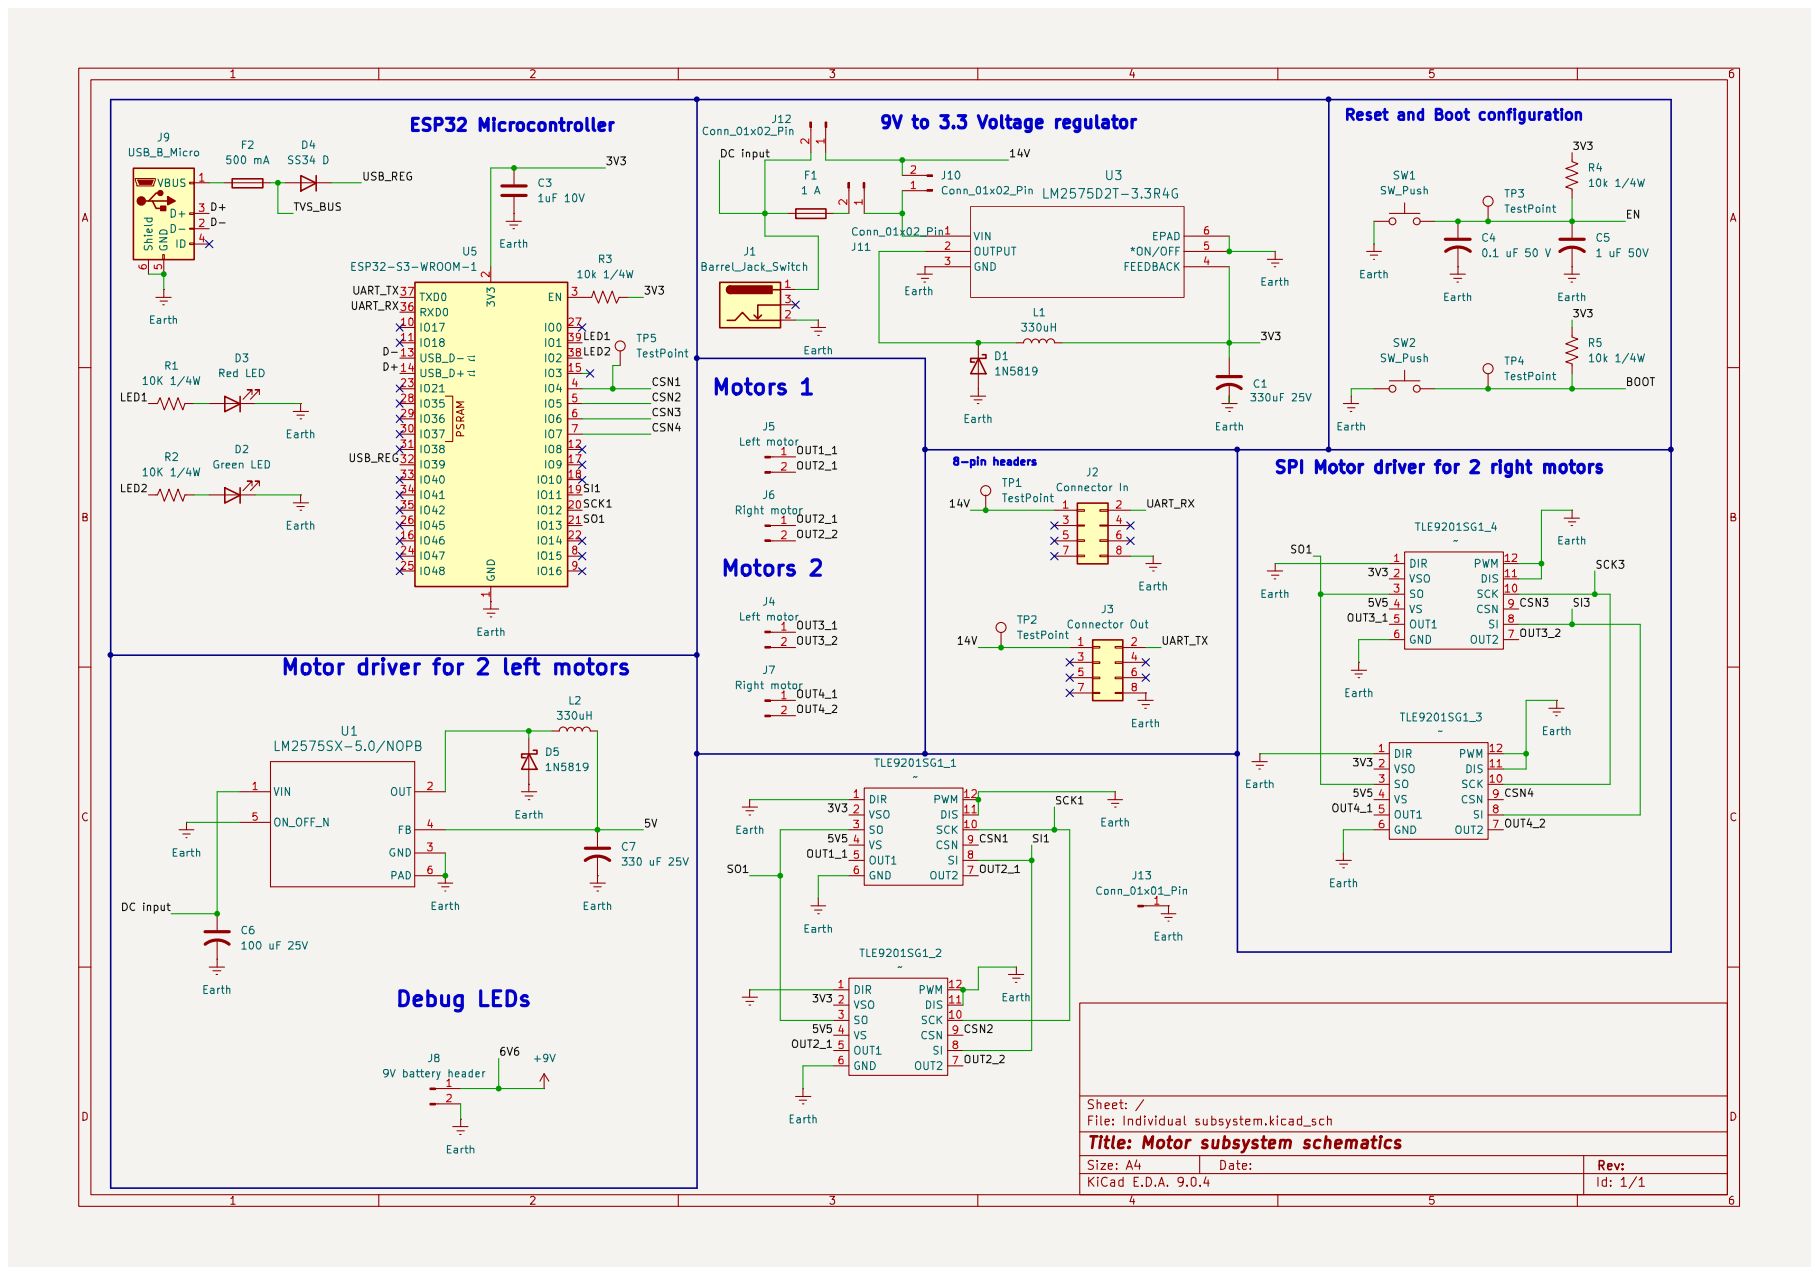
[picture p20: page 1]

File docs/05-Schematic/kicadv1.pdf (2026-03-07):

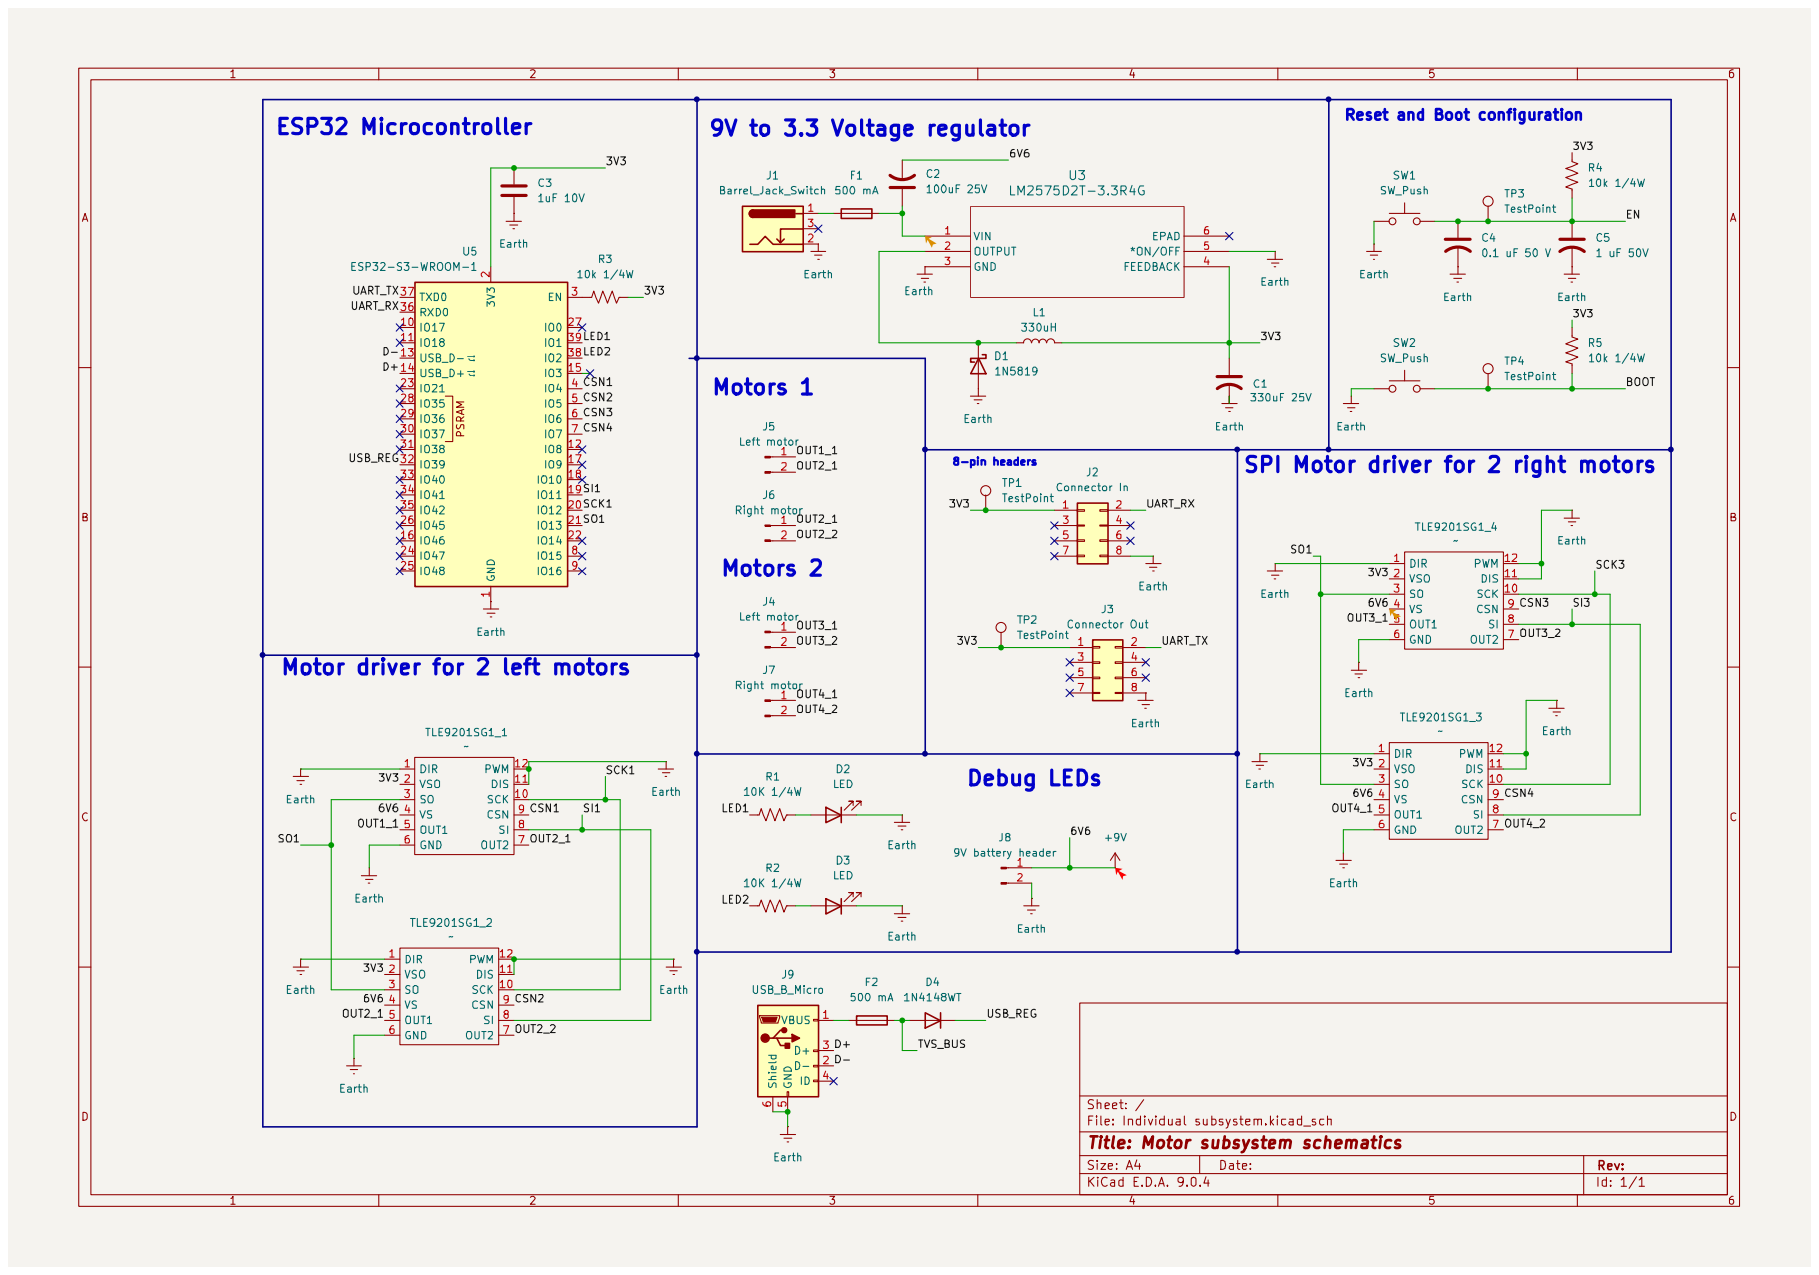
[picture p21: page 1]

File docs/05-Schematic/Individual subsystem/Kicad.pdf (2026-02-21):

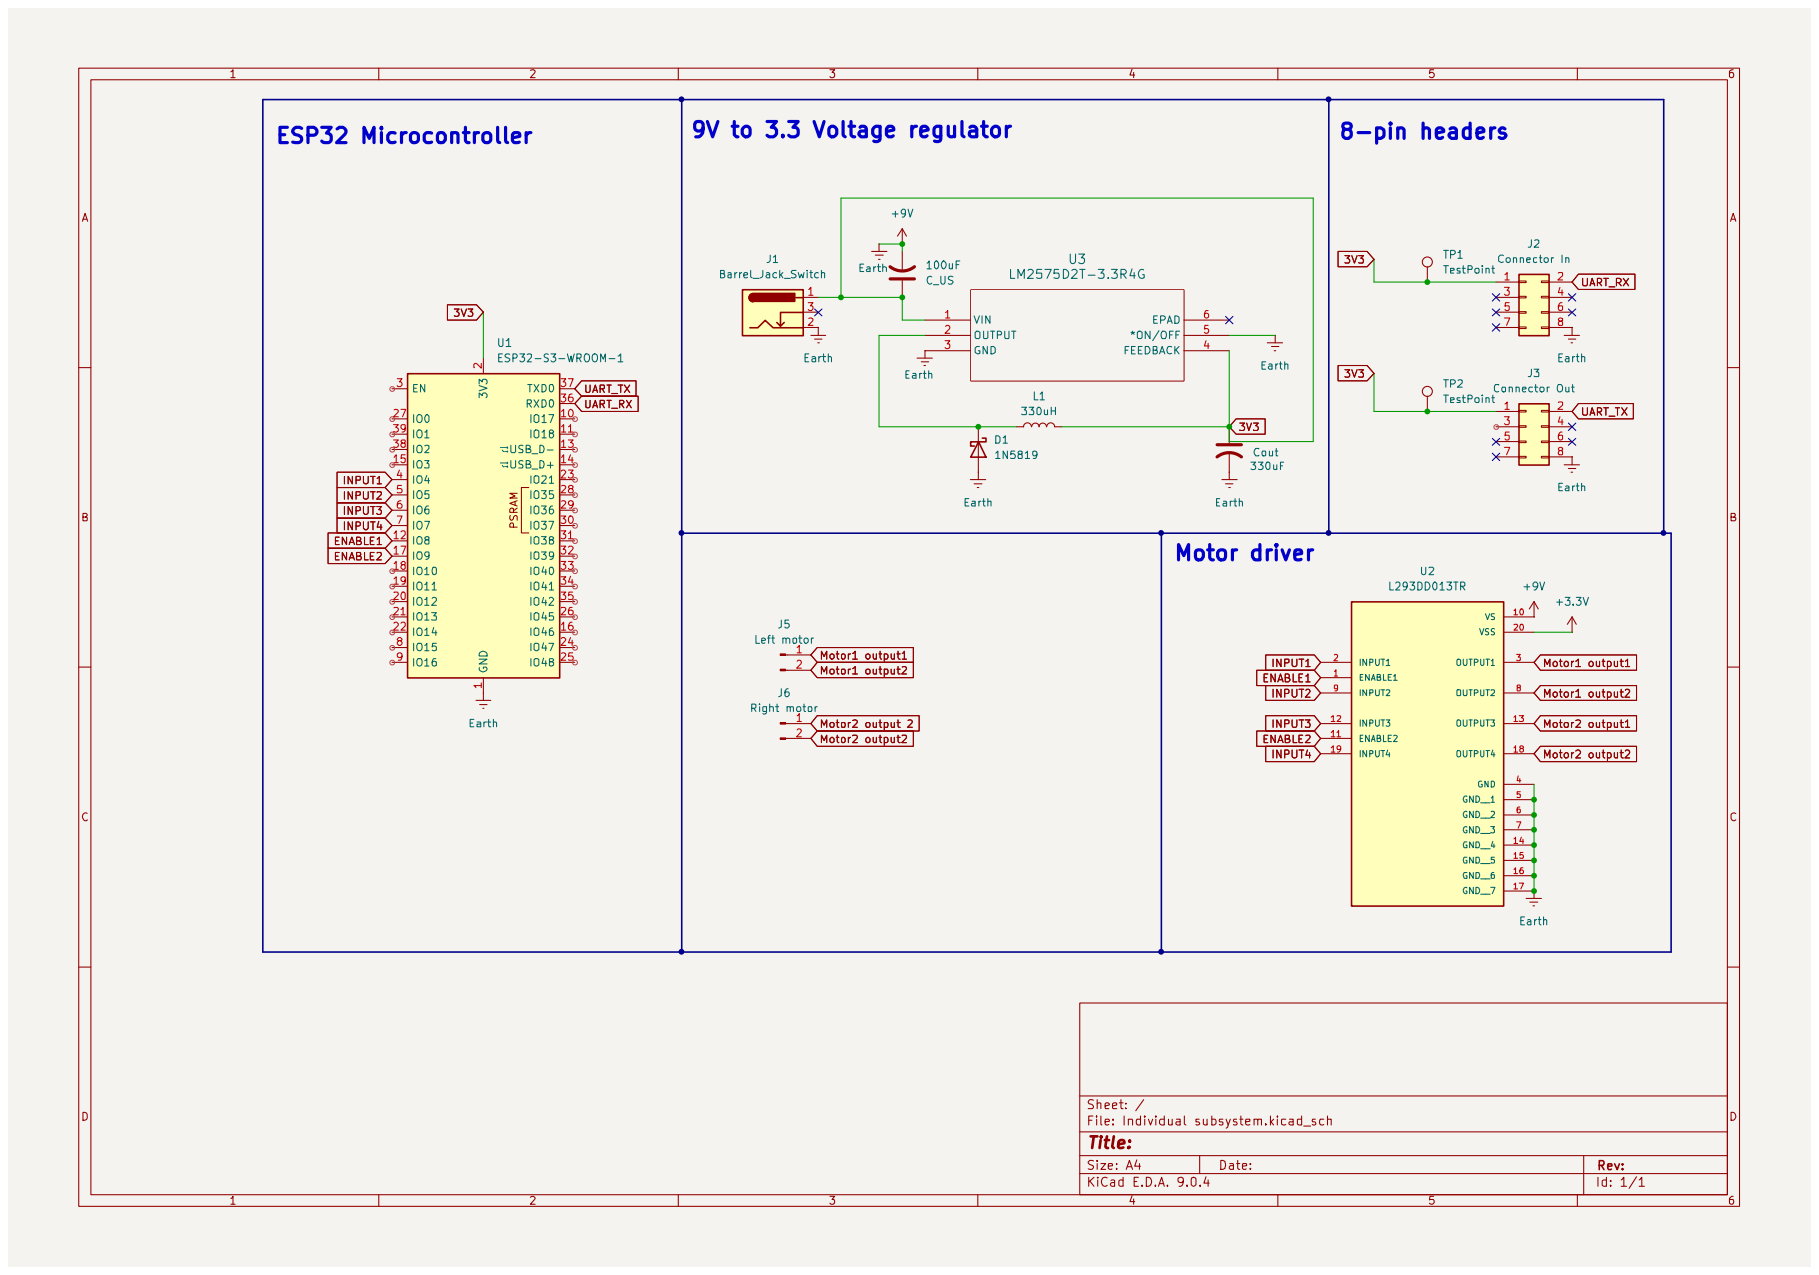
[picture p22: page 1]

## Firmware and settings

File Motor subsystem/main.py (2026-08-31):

import ssl
import time
import uasyncio as asyncio
from machine import UART, Pin, SPI

from mqtt_as import MQTTClient, config as mqtt_cfg
from config import (
    MQTT_PASSWORD,
    MQTT_SERVER,
    MQTT_USER,
    TOPIC_C_TO_W,
    TOPIC_W_TO_C,
    WIFI_PASSWORD,
    WIFI_SSID,
)

try:
    from mqtt_local import wifi_led
except ImportError:
    def wifi_led(_state):
        pass


# ============================================================================
# MOTOR SUBSYSTEM (W) - MQTT + UART DAISY CHAIN
# Team 202 - Asadbek - Motor/Wheel Subsystem
# ============================================================================

# ---------------------------------------------------------------------------
# SPI Configuration for Motor Control
# ---------------------------------------------------------------------------

SCK_PIN  = 12
MOSI_PIN = 11
MISO_PIN = 13
CS_PIN1  = 5
CS_PIN2  = 6
CS_PIN3  = 7
CS_PIN4  = 8

spi = SPI(
    2,
    baudrate=1_000_000,
    polarity=0,
    phase=1,
    sck=Pin(SCK_PIN),
    mosi=Pin(MOSI_PIN),
    miso=Pin(MISO_PIN),
)

cs1 = Pin(CS_PIN1, Pin.OUT)
cs2 = Pin(CS_PIN2, Pin.OUT)
cs3 = Pin(CS_PIN3, Pin.OUT)
cs4 = Pin(CS_PIN4, Pin.OUT)

for cs_pin in (cs1, cs2, cs3, cs4):
    cs_pin.value(1)

time.sleep(0.1)

WR_FORWARD = 0b11111111
WR_REVERSE = 0b11111101
WR_STOP    = 0b11111000

# ---------------------------------------------------------------------------
# UART Configuration for Daisy Chain to other subsystems
# ---------------------------------------------------------------------------

UART_DAISY_ID   = 1
UART_DAISY_TX   = 43
UART_DAISY_RX   = 44
UART_DAISY_BAUD = 9600

uart_daisy = UART(UART_DAISY_ID, baudrate=UART_DAISY_BAUD, tx=UART_DAISY_TX, rx=UART_DAISY_RX)
uart_daisy.init(UART_DAISY_BAUD, bits=8, parity=None, stop=1)

# ---------------------------------------------------------------------------
# Protocol Constants
# ---------------------------------------------------------------------------

PREFIX = b"AZ"
SUFFIX = b"YB"

MY_ID    = ord("w")
HMI_ID   = ord("h")
BCAST_ID = ord("X")
TEAM_IDS = {ord("h"), ord("c"), ord("w"), ord("p"), ord("a"), ord("m"), ord("t")}

MAX_DATA_LENGTH   = 58
MAX_PACKET_LENGTH = 2 + 1 + 1 + MAX_DATA_LENGTH + 2

# ---------------------------------------------------------------------------
# LEDs
# ---------------------------------------------------------------------------

led_red       = Pin(10, Pin.OUT)
led_green     = Pin(9, Pin.OUT)
led_broadcast = Pin(1, Pin.OUT)

# ---------------------------------------------------------------------------
# State / Buffers
# ---------------------------------------------------------------------------

motor_running          = False
motor_direction        = "STOPPED"
last_motion_command_ms = 0
MOTOR_FAILSAFE_MS      = 350

# Demo runs once: triggered by the first Start broadcast from Jacob.
demo_running = False

rx_buffer_daisy = b""
mqtt_client     = None


# ---------------------------------------------------------------------------
# Helpers
# ---------------------------------------------------------------------------

def id_to_char(value):
    try:
        return chr(value)
    except Exception:
        return "?"


def blink(pin, duration_ms=100):
    pin.value(1)
    time.sleep_ms(duration_ms)
    pin.value(0)


def blink_red():
    blink(led_red)


def blink_green():
    blink(led_green)


# ---------------------------------------------------------------------------
# Motor Control
# ---------------------------------------------------------------------------

def write_one(cs_pin, cmd_byte):
    cs_pin.value(0)
    time.sleep_us(2)
    spi.write(bytearray([cmd_byte]))
    time.sleep_us(2)
    cs_pin.value(1)
    time.sleep_us(2)


def set_all_motors(cmd_byte, direction_label):
    global motor_running, motor_direction

    for cs_pin in (cs1, cs2, cs3, cs4):
        write_one(cs_pin, cmd_byte)

    motor_running   = direction_label != "STOPPED"
    motor_direction = direction_label


def set_h_bridge_spi(direction_forward):
    global last_motion_command_ms

    if direction_forward:
        set_all_motors(WR_FORWARD, "FORWARD")
    else:
        set_all_motors(WR_REVERSE, "BACKWARD")
    last_motion_command_ms = time.ticks_ms()


def stop_all_motors():
    global last_motion_command_ms

    set_all_motors(WR_STOP, "STOPPED")
    last_motion_command_ms = 0


def motor_right():
    global motor_running, motor_direction, last_motion_command_ms

    write_one(cs1, WR_FORWARD)
    write_one(cs2, WR_REVERSE)
    write_one(cs3, WR_FORWARD)
    write_one(cs4, WR_REVERSE)

    motor_running          = True
    motor_direction        = "RIGHT"
    last_motion_command_ms = time.ticks_ms()


def motor_left():
    global motor_running, motor_direction, last_motion_command_ms

    write_one(cs1, WR_REVERSE)
    write_one(cs2, WR_FORWARD)
    write_one(cs3, WR_REVERSE)
    write_one(cs4, WR_FORWARD)

    motor_running          = True
    motor_direction        = "LEFT"
    last_motion_command_ms = time.ticks_ms()


# ---------------------------------------------------------------------------
# Demo sequence
# Triggered by the first Start broadcast from Jacob. Waits 10 s, then drives
# FORWARD 5 s, RIGHT 5 s, LEFT 5 s. The motor command is re-sent every 200 ms
# so the 350 ms failsafe can't stop it mid-leg.
# ---------------------------------------------------------------------------

async def _drive_for(action, label, duration_ms):
    print(">>> DEMO:", label, "for", duration_ms, "ms")
    deadline = time.ticks_add(time.ticks_ms(), duration_ms)
    while time.ticks_diff(deadline, time.ticks_ms()) > 0:
        action()
        await asyncio.sleep_ms(200)


async def demo_sequence():
    global demo_running
    if demo_running:
        return
    demo_running = True

    print("\n" + "=" * 50)
    print(">>> DEMO ARMED - waiting 10 s before motion")
    print("=" * 50)
    await asyncio.sleep(10)

    await _drive_for(lambda: set_h_bridge_spi(True), "FORWARD", 5000)
    await _drive_for(motor_right,                    "RIGHT",   5000)
    await _drive_for(motor_left,                     "LEFT",    5000)

    stop_all_motors()
    print(">>> DEMO COMPLETE")


# ---------------------------------------------------------------------------
# Packet Utilities
# ---------------------------------------------------------------------------

def validate_packet(packet):
    if not isinstance(packet, (bytes, bytearray)):
        print("ERROR: Packet is not bytes")
        blink_red()
        return False

    packet = bytes(packet).strip()

    if len(packet) < 6:
        print("ERROR: Packet too short")
        blink_red()
        return False

    if len(packet) > MAX_PACKET_LENGTH:
        print("ERROR: Packet too long")
        blink_red()
        return False

    if not packet.startswith(PREFIX) or not packet.endswith(SUFFIX):
        print("ERROR: Bad prefix/suffix")
        blink_red()
        return False

    sender = packet[2]
    if sender not in TEAM_IDS:
        print("ERROR: Unknown sender '%s'" % id_to_char(sender))
        blink_red()
        return False

    return True


def parse_packet(packet):
    sender   = packet[2]
    receiver = packet[3]
    data     = packet[4:-2].decode("utf-8", "ignore")
    return sender, receiver, data


def build_packet(receiver, data):
    if isinstance(receiver, str):
        receiver = ord(receiver)

    payload = data.encode("utf-8")
    if len(payload) > MAX_DATA_LENGTH:
        print("WARNING: Data too long, truncating")
        payload = payload[:MAX_DATA_LENGTH]

    return PREFIX + bytes([MY_ID, receiver]) + payload + SUFFIX


# ---------------------------------------------------------------------------
# Command Processing
# ---------------------------------------------------------------------------

def process_motor_command(sender, data):
    """
    Returns (response_receiver, response_data) or None.
    """
    try:
        parts = data.split(":")

        # Bluetooth check
        if len(parts) >= 3 and parts[0] == "BT" and parts[1] == "S":
            bt_value = parts[2].rstrip(";")
            if bt_value == "check":
                blink_green()
                print(">>> BLUETOOTH CHECK RECEIVED")
                return ord("c"), "BT:S:T;"
            return ord("c"), "BT:S:F;"

        # Wheel drive commands
        if len(parts) >= 3 and parts[0] == "WD" and parts[1] == "S":
            direction = parts[2].rstrip(";").upper()

            print("\n" + "=" * 50)
            print("MOTOR COMMAND FROM '%s'" % id_to_char(sender))
            print("Data:", data)
            print("Direction:", direction)
            print("=" * 50)

            if direction == "F":
                set_h_bridge_spi(True)
                blink_green()
                print(">>> MOTORS: FORWARD")
                return None

            if direction == "B":
                set_h_bridge_spi(False)
                blink_green()
                print(">>> MOTORS: BACKWARD")
                return None

            if direction == "R":
                motor_right()
                blink_green()
                print(">>> MOTORS: RIGHT TURN")
                return None

            if direction == "L":
                motor_left()
                blink_green()
                print(">>> MOTORS: LEFT TURN")
                return None

            if direction == "S":
                stop_all_motors()
                blink_red()
                print(">>> MOTORS: STOPPED")
                return None

            print(">>> Unknown direction:", direction)
            return None

        # Start broadcast from Jacob - acknowledge directly to him AND
        # kick off the 10s-then-drive demo (only the first time).
        if len(parts) >= 3 and parts[0] == "ST" and parts[1] == "S":
            blink_green()
            print(">>> START MESSAGE RECEIVED FROM '%s'" % id_to_char(sender))
            if not demo_running:
                asyncio.create_task(demo_sequence())
            return HMI_ID, "ST:S:WheelReady;"

        return None

    except Exception as exc:
        print("ERROR processing command:", exc)
        stop_all_motors()
        return None


# ---------------------------------------------------------------------------
# Packet Handling
# ---------------------------------------------------------------------------

async def handle_packet(packet):
    packet = bytes(packet).strip()

    if not validate_packet(packet):
        print("REJECTED:", packet)
        return

    sender, receiver, data = parse_packet(packet)

    # Discard messages from self
    if sender == MY_ID:
        print("\n" + "*" * 50)
        print(">>> MESSAGE FROM SELF - DISCARDING")
        print(">>> Packet:", packet.decode("utf-8", "ignore"))
        print("*" * 50 + "\n")
        blink_red()
        return

    # Message for me or broadcast
    if receiver == MY_ID or receiver == BCAST_ID:
        print("\n" + "#" * 60)
        print("### MESSAGE FOR WHEEL SUBSYSTEM ###")
        print("### From:", id_to_char(sender))
        print("### To  :", id_to_char(receiver))
        print("### Data:", data)
        print("### Full:", packet.decode("utf-8", "ignore"))
        print("#" * 60)

        if receiver == BCAST_ID:
            print(">>> BROADCAST RECEIVED - Turning on IO1 LED")
            led_broadcast.value(1)
            await asyncio.sleep_ms(500)
            led_broadcast.value(0)
        else:
            for _ in range(3):
                led_green.value(1)
                await asyncio.sleep_ms(100)
                led_green.value(0)
                await asyncio.sleep_ms(100)

        response = process_motor_command(sender, data)

        # Send the response over MQTT regardless of whether the original
        # was unicast or a broadcast - the Start ack to Jacob has to go out
        # even though he sent us a broadcast.
        if response and mqtt_client:
            response_receiver, response_data = response
            response_packet = build_packet(response_receiver, response_data)
            print(">>> Sending response via MQTT to '%s': %s" %
                  (id_to_char(response_receiver), response_data))
            await mqtt_client.publish(TOPIC_W_TO_C, response_packet, qos=1)

        # Forward broadcast down the UART chain
        if receiver == BCAST_ID:
            print(">>> FORWARDING BROADCAST TO DAISY CHAIN")
            uart_daisy.write(packet + b"\r\n")

        return

    # Message for another subsystem - forward via UART
    print("\n" + ">" * 50)
    print(">>> FORWARDING TO DAISY CHAIN")
    print(">>> From '%s' to '%s'" % (id_to_char(sender), id_to_char(receiver)))
    print(">>> Data:", data)
    print(">>> Full:", packet.decode("utf-8", "ignore"))
    print(">" * 50 + "\n")

    uart_daisy.write(packet + b"\r\n")


# ---------------------------------------------------------------------------
# MQTT -> Motor (receive from Communication)
# ---------------------------------------------------------------------------

def mqtt_sub_cb(topic, msg, retained):
    try:
        topic_name = topic.decode() if isinstance(topic, (bytes, bytearray)) else str(topic)
    except Exception:
        topic_name = str(topic)

    print("\n[MQTT] Received from topic:", topic_name)
    print("[MQTT] Message:", msg)
    asyncio.create_task(handle_packet(msg))


# ---------------------------------------------------------------------------
# UART Daisy Chain -> MQTT (receive from other subsystems)
# ---------------------------------------------------------------------------

async def publish_uart_packet(packet):
    if packet and mqtt_client:
        print("\n[UART DAISY] Received packet from subsystems")
        print("[UART DAISY] Sending to MQTT:", packet)
        await mqtt_client.publish(TOPIC_W_TO_C, packet, qos=1)


async def uart_daisy_task():
    global rx_buffer_daisy

    while True:
        if uart_daisy.any():
            chunk = uart_daisy.read()
            if chunk:
                rx_buffer_daisy += chunk

                while True:
                    start_idx = rx_buffer_daisy.find(PREFIX)
                    if start_idx == -1:
                        if len(rx_buffer_daisy) > MAX_PACKET_LENGTH * 2:
                            rx_buffer_daisy = b""
                        break

                    if start_idx > 0:
                        rx_buffer_daisy = rx_buffer_daisy[start_idx:]

                    end_idx = rx_buffer_daisy.find(SUFFIX, 4)
                    if end_idx == -1:
                        if len(rx_buffer_daisy) > MAX_PACKET_LENGTH * 2:
                            rx_buffer_daisy = rx_buffer_daisy[-MAX_PACKET_LENGTH:]
                        break

                    packet = rx_buffer_daisy[:end_idx + len(SUFFIX)]
                    rx_buffer_daisy = rx_buffer_daisy[end_idx + len(SUFFIX):]

                    if validate_packet(packet):
                        await publish_uart_packet(packet)
        else:
            await asyncio.sleep_ms(1)


async def motor_failsafe_task():
    while True:
        if motor_running and last_motion_command_ms:
            elapsed = time.ticks_diff(time.ticks_ms(), last_motion_command_ms)
            if elapsed >= MOTOR_FAILSAFE_MS:
                print(">>> MOTOR FAILSAFE: auto-stop")
                stop_all_motors()
                blink_red()
        await asyncio.sleep_ms(50)


# ---------------------------------------------------------------------------
# WiFi / MQTT Handlers
# ---------------------------------------------------------------------------

async def wifi_han(state):
    wifi_led(not state)
    print("[WiFi]", "UP" if state else "DOWN")
    await asyncio.sleep(1)


async def conn_han(cli):
    await cli.subscribe(TOPIC_C_TO_W, 1)
    print("[MQTT] Subscribed to C->W:", TOPIC_C_TO_W)


# ---------------------------------------------------------------------------
# Main
# ---------------------------------------------------------------------------

async def main(cli):
    global mqtt_client
    mqtt_client = cli

    try:
        await mqtt_client.connect()
        print("[SUCCESS] MQTT connected")
    except Exception as exc:
        print("[ERROR] MQTT connect failed:", exc)
        return

    asyncio.create_task(uart_daisy_task())
    asyncio.create_task(motor_failsafe_task())

    print("\n" + "=" * 70)
    print(" " * 15 + "MOTOR SUBSYSTEM READY")
    print("=" * 70)
    print("My ID: 'w' (Wheel/Motor)")
    print("MQTT Topics:")
    print("  Receive (C->W):", TOPIC_C_TO_W)
    print("  Send (W->C)   :", TOPIC_W_TO_C)
    print("UART Daisy Chain: TX=%d, RX=%d, Baud=%d" % (UART_DAISY_TX, UART_DAISY_RX, UART_DAISY_BAUD))
    print("Motors initialized and ready.")
    print("Demo: triggered on first ST:S:Start; from 'h' (Jacob)")
    print("=" * 70 + "\n")

    for _ in range(3):
        led_green.value(1)
        led_red.value(1)
        await asyncio.sleep_ms(200)
        led_green.value(0)
        led_red.value(0)
        await asyncio.sleep_ms(200)

    while True:
        await asyncio.sleep(5)


# ---------------------------------------------------------------------------
# MQTT Configuration
# ---------------------------------------------------------------------------

mqtt_cfg["server"]  = MQTT_SERVER
mqtt_cfg["ssid"]    = WIFI_SSID
mqtt_cfg["wifi_pw"] = WIFI_PASSWORD
mqtt_cfg["ssl"]     = True

try:
    with open("certs/cert26/student_key.pem", "rb") as f:
        key = f.read()
    with open("certs/cert26/student_crt.pem", "rb") as f:
        cert = f.read()
    with open("certs/cert26/ca_crt.pem", "rb") as f:
        ca = f.read()

    mqtt_cfg["ssl_params"] = {
        "cert"            : cert,
        "key"             : key,
        "cadata"          : ca,
        "server_hostname" : MQTT_SERVER,
        "cert_reqs"       : ssl.CERT_REQUIRED,
    }
    print("[SSL] Certificates loaded successfully")
except Exception as exc:
    print("[ERROR] Failed to load SSL certificates:", exc)
    print("Make sure certs/cert26 contains student_key.pem, student_crt.pem, and ca_crt.pem")

mqtt_cfg["time_server"]         = MQTT_SERVER
mqtt_cfg["time_server_timeout"] = 10
mqtt_cfg["subs_cb"]             = mqtt_sub_cb
mqtt_cfg["wifi_coro"]           = wifi_han
mqtt_cfg["connect_coro"]        = conn_han
mqtt_cfg["clean"]               = True
mqtt_cfg["user"]                = MQTT_USER
mqtt_cfg["password"]            = MQTT_PASSWORD


# ---------------------------------------------------------------------------
# Run
# ---------------------------------------------------------------------------

MQTTClient.DEBUG = True
client = MQTTClient(mqtt_cfg)

try:
    asyncio.run(main(client))
finally:
    stop_all_motors()
    led_red.value(0)
    led_green.value(0)
    led_broadcast.value(0)
    client.close()
    asyncio.new_event_loop()
    print("\nMotor subsystem stopped")

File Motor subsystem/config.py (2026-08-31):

# ------------------------------------------------------------
# Team / Namespace
# ------------------------------------------------------------

TEAM = 'EGR314/Team202/CGE'


# ------------------------------------------------------------
# MQTT Topics
# ------------------------------------------------------------

# Directional topics (MAIN SYSTEM)
TOPIC_C_TO_W = TEAM + '/c_to_w'   # Controller → Rover
TOPIC_W_TO_C = TEAM + '/w_to_c'   # Rover → Controller

# Optional: keep lab/demo topics (not required for final system)
TOPIC_HB  = TEAM + '/heartbeat'
TOPIC_PUB = TEAM + '/pub'
TOPIC_SUB = TEAM + '/sub'


# ------------------------------------------------------------
# MQTT Server Credentials
# ------------------------------------------------------------

MQTT_SERVER   = '34.210.232.255'
MQTT_USER     = 'student'
MQTT_PASSWORD = 'egr3x4'


# ------------------------------------------------------------
# WiFi Credentials
# ------------------------------------------------------------

WIFI_SSID = 'asu guest'
WIFI_PASSWORD = ''

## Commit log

2026-02-21 do it
    [Individual subsystem.kicad_pcb, Individual subsystem.kicad_sch]
2026-03-07 stage all
2026-03-10 pcb change
    [Individual subsystem-B_Cu.gbr, Individual subsystem-B_Mask.gbr, Individual subsystem-B_Silkscreen.gbr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]
2026-03-28 all of them
    [Individual subsystem-B_Cu.gbr, Individual subsystem-B_Mask.gbr, Individual subsystem-B_Silkscreen.gbr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]
2026-05-03 update on schematics, PCB, code config
2026-05-04 Revise README for EGR 314 individual datasheet
    Updated the README to reflect the individual datasheet for EGR 314 class and provided details about the PCB board and its functionalities.
2026-05-04 final schematic and PCB
2026-05-04 BOM update
2026-05-05 fix schematic
2026-05-05 3D view of the PCB
2026-05-05 folder changes
    [PowerBudgetExample.xlsx]
2026-05-05 power budget
2026-05-05 few fix
    [PowerBudgeexcel.xlsx]
2026-05-05 fixed PCB
2026-08-31 change to readme
    [results.csv]
